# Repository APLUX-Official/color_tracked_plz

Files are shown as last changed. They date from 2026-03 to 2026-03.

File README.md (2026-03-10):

# 🎯 Color Tracked PTZ (Pan-Tilt-Zoom)

HSV color tracking PTZ based on **Arduino UNO Q**. OpenCV identifies the target color → PID closed-loop control algorithm calculates the error → MG996R servos follow in real time, with a cyberpunk-style Web console provided.

## ✨ Functional Features

| Feature | Description |
| --- | --- |
| 🎨 Dynamic Color Selection | Hue slider + 6 color presets (Yellow/Red/Green/Blue/Orange/Purple) for real-time switching of the tracked color |
| 🤖 PID Automatic Tracking | Dual-axis independent PID closed-loop control, including deadband hysteresis, integral Anti-Windup, and EMA coordinate filtering |
| 📊 PID Online Parameter Tuning | Four-parameter sliders (Kp/Ki/Kd/deadband) + 4 preset schemes (Default/Pure P/Conservative/Aggressive), taking effect in real time |
| 🕹️ Manual Control | Direct control via sliders for Pan (0-180°) / Tilt (30-150°) |
| 🔧 Servo Neutral Calibration | Fine adjustment (±1°/±5°) + one-click return to 90° neutral position, facilitating rocker arm installation |
| 📹 Real-Time Video | Base64 JPEG streaming (~25fps) with tracking markers displayed directly in the browser |

## 🔌 Hardware Connection

| Component | Pin  | Description |
| --- | ---- | --- |
| Pan Servo (MG996R)  | D3 | Horizontal rotation (0°-180°) |
| Tilt Servo (MG996R) | D11  | Vertical tilt (30°-150°) |
| USB Camera | USB  | 320×240 MJPG |

## 📁 Project Structure

```
color_tracked_plz/
├── app.yaml           # Arduino App Configuration
├── assets/
│   └── index.html     # Single-file Web Console (CSS + HTML + JS, ~930 lines)
├── python/
│   └── main.py        # OpenCV Vision + PID Control + WebUI Service (~270 lines)
└── sketch/
    ├── sketch.ino     # Manual 50Hz PWM Servo Driver (~65 lines)
    └── sketch.yaml    # Sketch Configuration (Arduino Zephyr UNO Q)
```

## 🧠 Core Algorithms

### PID Closed-Loop Control

Dual-axis independent PID controllers convert pixel errors into servo angle correction values:

$$u(k) = K_p \cdot e(k) + K_i \cdot \sum_{j=0}^{k} e(j) + K_d \cdot [e(k) - e(k-1)]$$

- **Proportional Term (P)**: Larger error leads to greater correction, providing fast response
- **Integral Term (I)**: Accumulates historical errors to eliminate steady-state deviation, with Anti-Windup limiting (±500)
- **Derivative Term (D)**: Detects the rate of error change to suppress overshoot and oscillation
- **Deadband Hysteresis**: No action when error < 20px; reactivation requires error exceeding 26px to avoid edge jitter
- **EMA Low-Pass Filter**: Exponential Moving Average (α=0.4) on detected coordinates to smooth inter-frame noise

### Color Threshold Segmentation

Color segmentation and centroid calculation based on the HSV color space:

```
BGR → HSV Conversion → inRange Threshold Segmentation → Erosion/Dilation Denoising
→ findContours Contour Extraction → Largest Contour → minEnclosingCircle Centroid Localization
```

Red color automatically handles hue wrapping (merged dual masks for H≈170°~10°).

### Manual PWM Servo Driving

Instead of using the Servo library, 50Hz pulses are generated manually in `loop()`:

```
Angle → Pulse Width: pulse = 500 + (angle × 2000 / 180) μs
0° → 500μs | 90° → 1500μs | 180° → 2500μs
```

## 🚀 Usage Instructions

1. **Upload Sketch** — Compile and upload the `sketch/` directory to UNO Q
2. **Start App** — Run the project in Arduino App Lab
3. **Open Console** — Access `http://<UNO_Q_IP>:7000` in a browser
4. **Select Color** — Choose the color to track using the Hue slider or preset color blocks
5. **Enable Tracking** — Toggle the "Auto Tracking" switch to make the PTZ follow the target automatically

### 🔧 Servo Calibration

Use this when assembling for the first time or replacing the rocker arm:

1. Click **"Start Calibration"** → Both axes automatically return to the 90° neutral position
2. Use the **±1 / ±5** buttons to fine-tune to the servo's physical neutral position
3. Install the servo rocker arm at the current angle
4. Click **"Finish Calibration"** to exit

> During calibration, auto tracking is forcibly disabled to ensure manual fine-tuning is not interfered with.

### 🎯 PID Tuning Guide

| Phenomenon | Adjustment Suggestion |
| --- | --- |
| Too slow response | Increase Kp |
| Jitter/Oscillation | Increase Kd or decrease Kp |
| Target centered but with deviation | Increase Ki |
| Jitter near the center | Increase deadband |

Quick reference for four preset schemes:

| Preset | Kp | Ki | Kd | Deadband | Application Scenario |
| --- | ----- | --- | ----- | --- | --- |
| Default | 0.035 | 0.0005 | 0.025 | 20 | General balance |
| Pure P | 0.08  | 0 | 0 | 10 | Fast response with steady-state error |
| Conservative | 0.02  | 0.002  | 0.03  | 25 | Stable tracking |
| Aggressive | 0.06  | 0.003  | 0.04  | 10 | Sensitive tracking (possible overshoot) |

## 🛠️ Technology Stack

- **Arduino Firmware**: Manual 50Hz PWM + RouterBridge remote call
- **Python Middleware**: OpenCV HSV color recognition + PID closed-loop control + EMA coordinate filtering + Base64 streaming
- **Web Frontend**: Single-file HTML (cyberpunk style), Socket.IO bidirectional communication
- **Communication Protocol**: RouterBridge (Python ↔ Arduino), Socket.IO (Browser ↔ Python)

<!--
 * @Author: WALT
 * @Date: 2026-02-09 19:36:03
-->

# 🎯 颜色追踪云台 (Color Tracked PTZ)

基于 **Arduino UNO Q** 的 HSV 颜色追踪云台。OpenCV 识别目标颜色 → PID 闭环控制算法计算误差 → MG996R 舵机实时跟随，同时提供赛博朋克风格 Web 控制台。

## ✨ 功能特性

| 功能 | 说明 |
|---|---|
| 🎨 动态选色 | Hue 滑条 + 6 色预设（黄/红/绿/蓝/橙/紫），实时切换追踪颜色 |
| 🤖 PID 自动追踪 | 双轴独立 PID 闭环控制，含死区迟滞、积分 Anti-Windup、EMA 坐标滤波 |
| 📊 PID 在线调参 | Kp/Ki/Kd/死区四参数滑块 + 4 种预设方案（默认/纯P/保守/激进），实时生效 |
| 🕹️ 手动控制 | Pan 0-180° / Tilt 30-150° 滑块直控 |
| 🔧 舵机中位校准 | ±1°/±5° 微调 + 一键回中 90°，方便安装摇臂 |
| 📹 实时视频 | Base64 JPEG 推流（~25fps），浏览器直接显示追踪标记 |

## 🔌 硬件连接

| 组件 | 引脚 | 说明 |
|---|---|---|
| Pan 舵机 (MG996R) | D3 | 水平旋转 0°-180° |
| Tilt 舵机 (MG996R) | D11 | 垂直俯仰 30°-150° |
| USB 摄像头 | USB | 320×240 MJPG |

## 📁 项目结构

```
color_tracked_plz/
├── app.yaml           # Arduino App 配置
├── assets/
│   └── index.html     # 单文件 Web 控制台 (CSS + HTML + JS, ~930行)
├── python/
│   └── main.py        # OpenCV 视觉 + PID 控制 + WebUI 服务 (~270行)
└── sketch/
    ├── sketch.ino     # 手动 50Hz PWM 舵机驱动 (~65行)
    └── sketch.yaml    # Sketch 配置 (Arduino Zephyr UNO Q)
```

## 🧠 核心算法

### PID 闭环控制

双轴独立 PID 控制器，将像素误差转换为舵机角度修正量：

$$u(k) = K_p \cdot e(k) + K_i \cdot \sum_{j=0}^{k} e(j) + K_d \cdot [e(k) - e(k-1)]$$

- **比例项 (P)**：误差越大修正越大，提供快速响应
- **积分项 (I)**：累积历史误差，消除稳态偏差，含 Anti-Windup 限幅 (±500)
- **微分项 (D)**：感知误差变化速率，抑制超调震荡
- **死区迟滞**：误差 < 20px 时不动作，需超过 26px 才重新激活，避免边缘抖动
- **EMA 低通滤波**：对检测坐标做指数移动平均（α=0.4），平滑帧间噪声

### 颜色阈值分割

基于 HSV 色彩空间的颜色分割与质心计算：

```
BGR → HSV 转换 → inRange 阈值分割 → 腐蚀/膨胀去噪
→ findContours 轮廓提取 → 最大轮廓 → minEnclosingCircle 质心定位
```

红色自动处理色相环绕（H≈170°~10°双 mask 合并）。

### 手动 PWM 舵机驱动

不使用 Servo 库，`loop()` 中手动生成 50Hz 脉冲：

```
角度 → 脉宽: pulse = 500 + (angle × 2000 / 180) μs
0° → 500μs | 90° → 1500μs | 180° → 2500μs
```

## 🚀 使用方法

1. **上传 Sketch** — 将 `sketch/` 编译上传到 UNO Q
2. **启动 App** — 在 Arduino App Lab 中运行本项目
3. **打开控制台** — 浏览器访问 `http://<UNO_Q_IP>:7000`
4. **选择颜色** — 用 Hue 滑条或预设色块选择要追踪的颜色
5. **开启追踪** — 打开 "自动追踪" 开关，云台自动跟随目标

### 🔧 舵机校准

首次组装或更换摇臂时使用：

1. 点击 **"开始校准"** → 两轴自动回中 90°
2. 用 **±1 / ±5** 按钮微调至舵机物理中位
3. 在当前角度安装舵机摇臂
4. 点击 **"完成校准"** 退出

> 校准时自动追踪会被强制关闭，确保手动微调不受干扰。

### 🎯 PID 调参指南

| 现象 | 调整建议 |
|---|---|
| 响应太慢 | 增大 Kp |
| 抖动/震荡 | 增大 Kd 或减小 Kp |
| 目标居中但有偏差 | 增大 Ki |
| 中心附近抖动 | 增大死区 |

四种预设方案速查：

| 预设 | Kp | Ki | Kd | 死区 | 适用场景 |
|---|-----|---|---|---|---|
| 默认 | 0.035 | 0.0005 | 0.025 | 20 | 通用平衡 |
| 纯P | 0.08 | 0 | 0 | 10 | 快速响应，有稳态误差 |
| 保守 | 0.02 | 0.002 | 0.03 | 25 | 平稳追踪 |
| 激进 | 0.06 | 0.003 | 0.04 | 10 | 灵敏追踪，可能超调 |

## 🛠️ 技术栈

- **Arduino 固件**：手动 50Hz PWM + RouterBridge 远程调用
- **Python 中台**：OpenCV HSV 颜色识别 + PID 闭环控制 + EMA 坐标滤波 + Base64 推流
- **Web 前端**：单文件 HTML（赛博朋克风），Socket.IO 双向通信
- **通信协议**：RouterBridge（Python ↔ Arduino），Socket.IO（浏览器 ↔ Python）

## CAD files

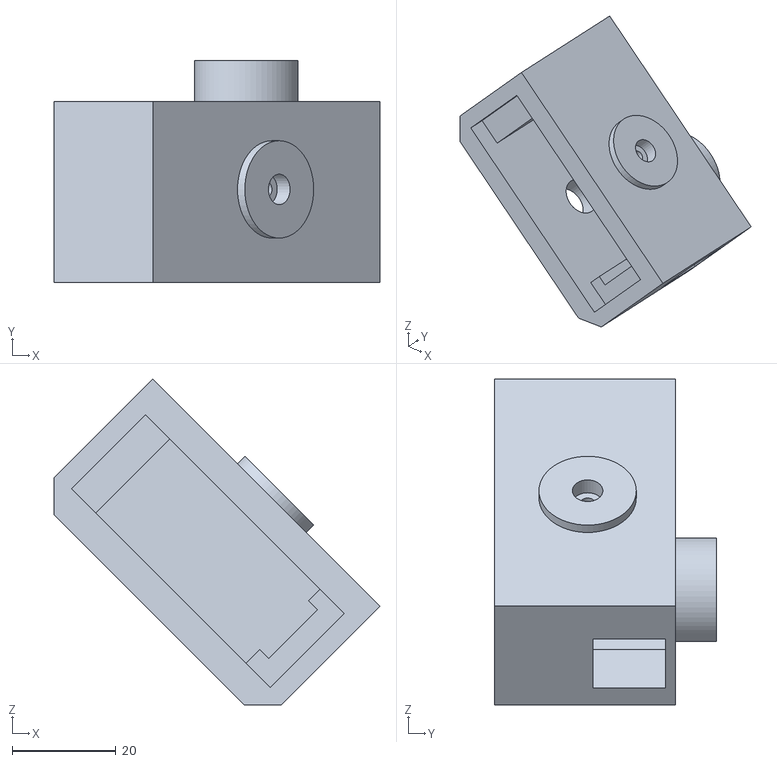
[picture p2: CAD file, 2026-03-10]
models/顶座.stl
62.9 x 42.9 x 62.9

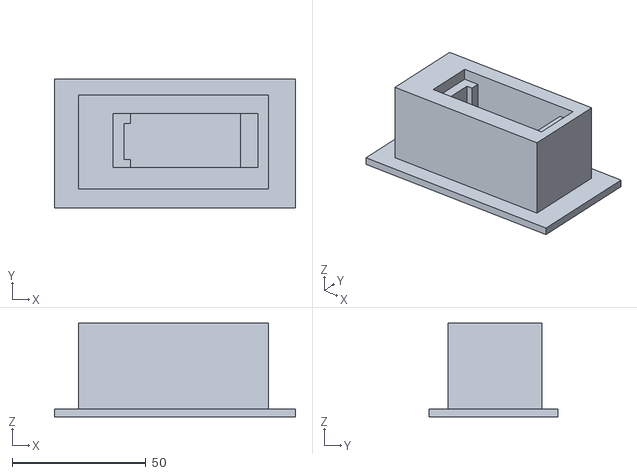
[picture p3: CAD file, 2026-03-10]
models/组合体.stl
90.0 x 48.0 x 35.0

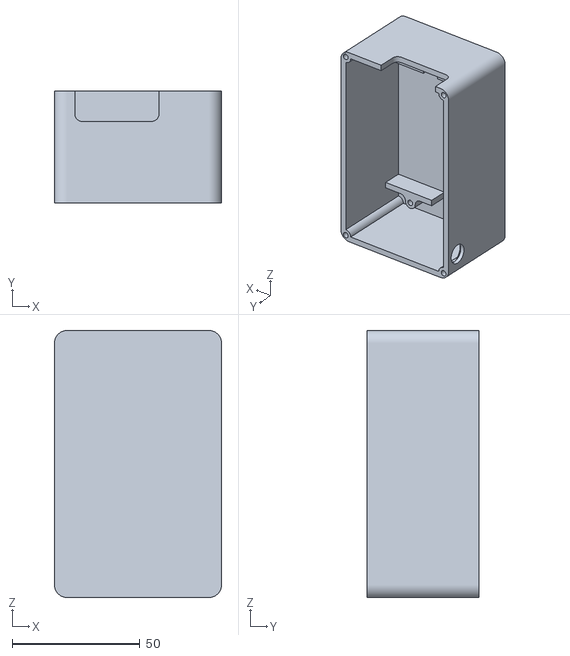
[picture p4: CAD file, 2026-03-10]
models/底座.stl
65.5 x 44.0 x 104.6

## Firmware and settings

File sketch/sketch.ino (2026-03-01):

/*
 * @Author: WALT
 * @Date: 2026-02-09 19:36:03
 */
// SPDX-FileCopyrightText: Copyright (C) ARDUINO SRL (http://www.arduino.cc)
// SPDX-License-Identifier: MPL-2.0

#include "Arduino_RouterBridge.h"

const int PIN_PAN = D3;   // Pan
const int PIN_TILT = D11; // Tilt

// 全局变量存脉宽 (默认中位 1500us)
volatile int pulse_pan = 1500;
volatile int pulse_tilt = 1500;

void setup() {
    pinMode(PIN_PAN, OUTPUT);
    pinMode(PIN_TILT, OUTPUT);

    Bridge.begin();
    // 注册两个函数供 Python 调用
    Bridge.provide("set_pan", update_pan);
    Bridge.provide("set_tilt", update_tilt);
}

void loop() {
    // === 手动生成双路 PWM (50Hz) ===
    
    // 1. Pan 脉冲
    digitalWrite(PIN_PAN, HIGH);
    delayMicroseconds(pulse_pan);
    digitalWrite(PIN_PAN, LOW);
    
    // 2. Tilt 脉冲
    digitalWrite(PIN_TILT, HIGH);
    delayMicroseconds(pulse_tilt);
    digitalWrite(PIN_TILT, LOW);
    
    // 3. 补足剩余时间
    int used_time = pulse_pan + pulse_tilt;
    if(20000 - used_time > 0) {
        delayMicroseconds(20000 - used_time);
    }
}

// 角度转脉宽辅助函数
int angle_to_pulse(int angle) {
    if (angle < 0) angle = 0;
    if (angle > 180) angle = 180;
    return 500 + (angle * 2000 / 180);
}

// Python 调用的函数
void update_pan(int angle) {
    pulse_pan = angle_to_pulse(angle);
}

void update_tilt(int angle) {
    pulse_tilt = angle_to_pulse(angle);
}
